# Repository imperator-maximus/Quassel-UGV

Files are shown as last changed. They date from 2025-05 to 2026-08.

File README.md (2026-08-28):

# 🚁 Quassel UGV - RTK-GPS + WitMotion Sensor Hub + WebApp

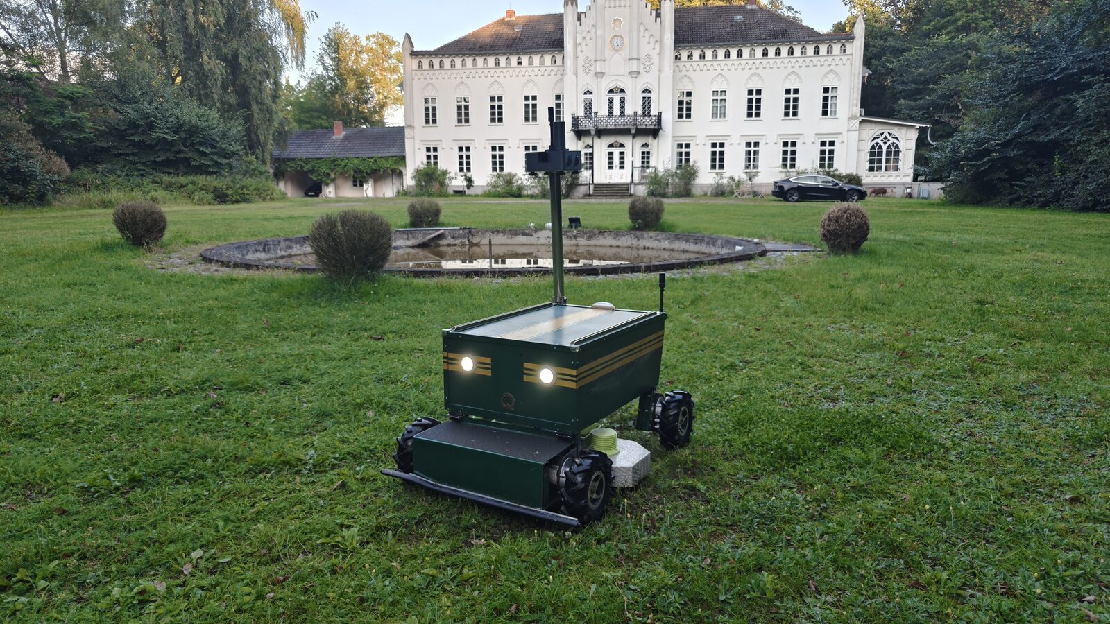
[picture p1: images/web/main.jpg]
Quassel UGV in the manor park


> Start here for the current vehicle: **[`CURRENT_PRODUCTION.md`](CURRENT_PRODUCTION.md)**
>
> More photos with descriptions: **[`images/README.md`](images/README.md)**

A professional autonomous UGV system with an Orange-Pi-based sensor hub, RTK-GPS positioning, WitMotion IMU orientation, redundant WiFi telemetry, direct ODrive USB control, and a real-time web interface.

> **Authoritative production state:** the GNSS receiver is attached to the
> Raspberry over USB serial and RTK corrections arrive by NTRIP. Both ODrive
> boards use two direct USB/Fibre links. The CAN bus and the separate SensorHub
> are removed, code included. Do not reintroduce either.
>
> Sections below that still describe the Orange Pi SensorHub are stale and
> await the physical details of the new arrangement.

## 🎯 Project Overview

This project implements a complete autonomous UGV system featuring:
- **Dual-antenna RTK-GPS** (Holybro UM982) for precise positioning and heading
- **WitMotion USB-IMU** for roll/pitch/yaw orientation
- **Direct ODrive USB control** with current, error and watchdog diagnostics
- **Redundant HTTP/WiFi SensorHub telemetry** over two persistent streams
- **Real-time Web Interface** with Bing Maps satellite view
- **Modular Architecture** with Orange Pi Zero 2W sensor hub and Pi 3 controller

### ✅ Project Status: **ACTIVE DEVELOPMENT**
- ✅ Sensor hub architecture (Orange Pi Zero 2W, RTK/IMU and WiFi telemetry)
- ✅ RTK-GPS + IMU integration
- ✅ Two direct ODrive USB/Fibre connections
- ✅ Web interface framework
- ✅ WitMotion-based IMU telemetry on the sensor hub

## 🏗️ System Architecture

### Hardware Architecture

```
┌─────────────────────────────────────────┐
│  MAST (Orange Pi Zero 2W)               │
│  ├─ Holybro UM982 (Dual-Antenna RTK)    │
│  │  └─ USB Serial (/dev/serial/by-id)   │
│  ├─ WitMotion USB-IMU                   │
│  │  └─ USB Serial (/dev/serial/by-id)   │
│  └─ SensorHub HTTP API                  │
└─────────────────────────────────────────┘
            │
            │ HTTP/WiFi telemetry
            ▼
┌─────────────────────────────────────────┐
│  CHASSIS (Pi 3 + Motor Control)         │
│  ├─ WebApp (Python-based)               │
│  ├─ 2× direct ODrive USB/Fibre          │
│  │  └─ 3 used axes by serial + index    │
│  └─ WLAN Access Point                   │
└─────────────────────────────────────────┘
            │
            │ WLAN
            ▼
    [ Browser-Client ]
```

### Production Transport Assignment

Everything hangs off the Raspberry directly. There is no bus and no second
computer in the loop.

| System | Active transport | Profile |
|---|---|---|
| GNSS receiver → Raspberry | USB serial | port via `/dev/serial/by-id` |
| RTK corrections → Raspberry | NTRIP over cellular | mountpoint `openrtk_mv` |
| Raspberry → ODrive boards | Two direct USB/Fibre links | serial number + axis index |

### Physical Vehicle Layout

- **Vehicle length**: approx. **115 cm**
- **Vehicle width incl. wheels**: approx. **79 cm**
- **Vehicle height without mast**: approx. **60 cm**
- **Additional mast height incl. enclosure**: approx. **70 cm**
- **Overall height with mast**: approx. **130 cm**
- **Payload / ride-on capability**: the platform is large and robust enough that **one person can ride on it**

**Sensor placement:**
- **Mast position**: rear left on the vehicle
- **Primary GPS antenna**: mounted on the mast, rear left, at approx. **130 cm** height
- **Secondary GPS antenna**: mounted rear right directly on the housing at approx. **60 cm** height
- **Distance between GPS antennas**: approx. **51 cm**
- **Side inset of both GPS antennas**: approx. **14 cm** inboard from the left/right vehicle edge
- **Rear inset of both GPS antennas**: approx. **10 cm** forward from the rear edge
- **IMU position**: mounted at the top of the mast

### Software Stack

**Orange Pi Zero 2W (Sensor Hub):**
| Component | Function | Interface |
|---|---|---|
| UM982 GPS | RTK Position + Dual-Antenna Heading | USB Serial /dev/serial/by-id |
| WitMotion USB-IMU | 9-DoF IMU incl. orientation frames | USB Serial |
| `sensor_hub_app.py` | Web API + redundant HTTP telemetry + sensor status | Systemd Service |

**Data Flow:**
- GPS-NMEA reading (pyserial)
- IMU data reading (pyserial / WitMotion binary protocol)
- Sensor telemetry (Position + Heading + Roll/Pitch/Yaw)
- Two persistent NDJSON telemetry streams over HTTP/WiFi

**Pi 3 (Controller + WebApp):**
| Component | Function |
|---|---|
| Python WebApp | Flask/FastAPI |
| ODrive USB/Fibre | Controls three axes and reads errors/current directly |
| SensorHub HTTP client | Receives RTK/IMU telemetry over WiFi |
| WebSocket/SSE | Real-time push to browser |
| Bing Maps API | Map display |

**WebApp Features:**
- 🗺️ Bing Maps Satellite View (Lübtheen-optimized)
- 📍 GPS Position (Live marker)
- 🧭 Heading Display (Dual-antenna)
- 📊 RTK Status (No Fix / Float / Fixed)
- 🛤️ Trail/Path (last N positions)
- 📐 Roll/Pitch/Yaw from IMU

## 🛠️ Development Tools (`tools/`)

Deployment and ODrive configuration utilities; see `tools/README.md`.

## 🚀 Quick Start

### 1. Install Dependencies on Raspberry Pi 3 (Controller)
```bash
# Install web framework and the GNSS serial dependency
pip3 install -r raspberry_pi/motor_controller/requirements.txt
```

### 3. Setup Sensor Hub (Orange Pi Zero 2W)
```bash
# Upload current sensor hub
scp -r sensor_hub nicolay@orangeugv:/home/nicolay/

# Follow the tested deploy guide
ssh nicolay@orangeugv
cd /home/nicolay/sensor_hub
sudo systemctl start sensor-hub.service
```

### 4. Setup Controller (Pi 3)
```bash
# Upload web app
scp web_app.py nicolay@raspberrycan:/home/nicolay/

# Start web interface
python3 web_app.py
# Access at http://raspberrycan:80
```

## 📋 Hardware Configuration

### Vehicle Geometry / Sensor Placement

- **Length**: approx. **115 cm**
- **Width incl. wheels**: approx. **79 cm**
- **Height without mast**: approx. **60 cm**
- **Mast incl. enclosure**: additional approx. **70 cm**
- **Mast location**: **rear left**
- **Upper GPS antenna**: rear left on mast, approx. **130 cm** above ground
- **Lower GPS antenna**: rear right on housing, approx. **60 cm** above ground
- **GPS antenna baseline**: approx. **51 cm**
- **Lateral antenna inset**: approx. **14 cm** from each outer side edge (`(0.79 m - 0.51 m) / 2`)
- **Rear antenna inset**: approx. **10 cm** from the rear edge
- **IMU**: mounted on top of the mast
- **Ride-on capability**: one person can ride on the vehicle

### Sensor Hub (Orange Pi Zero 2W)
- **MCU**: Allwinner H616
- **GPS**: Holybro UM982 (Dual-antenna RTK)
  - USB serial via `/dev/serial/by-id/...`
- **IMU**: WitMotion USB-IMU
  - USB serial via `/dev/serial/by-id/...`
- **Operating System**: DietPi / Debian-based
- **Network**: HTTP/WiFi to the Raspberry controller via the Fritzbox port forward

### Controller (Pi 3)
- **MCU**: Broadcom BCM2837 (ARM Cortex-A53 Quad-Core)
- **Mower interface**: two direct USB/Fibre links to ODrive Board A/B
- **Motor Control**: GPIO 18/19 (Hardware-PWM)
- **Operating System**: Raspberry Pi OS (Debian-based)
- **Network**: WiFi + SSH access (nicolay@raspberrycan)

### Sensor Hub Device Usage (Orange Pi Zero 2W)
**USB Devices:**
- **Holybro UM982**: USB serial GNSS (`/dev/serial/by-id/...`)
- **WitMotion IMU**: USB serial IMU (`/dev/serial/by-id/usb-1a86_USB_Serial-if00-port0`)

### GPIO Pin Configuration (Pi 3 - Controller)
**Motor Control:**
- **GPIO 18**: Right Motor PWM Output (Hardware-PWM)
- **GPIO 19**: Left Motor PWM Output (Hardware-PWM)

**Relay Control:**
- **GPIO 22**: Light Control Relay Output (HIGH = On, LOW = Off)
- **GPIO 23**: Mower Control Relay Output (HIGH = On, LOW = Off)

**Safety:**
- **GPIO 17**: Emergency Stop/Safety Switch Input (pulled high, active low)
- **GPIO 12**: Mower Speed PWM Output (24-100% Duty Cycle, 1000Hz, 3.3V GPIO)

### Mower Speed Control (PWM-to-Analog Conversion)

The mower speed control uses PWM-to-analog conversion via RC filter circuit:

**Circuit Configuration:**
```
GPIO12 (PWM) ----[1kΩ]----+-----> Analog Output (to Mower Controller)
                           |
                         [15µF]
                           |
                         GND
```

**PWM Specifications:**
- **Frequency**: 1000Hz
- **Duty Cycle Range**: 24-100% (optimized for 3.3V GPIO)
- **Output Voltage Range**: 0.8V - 3.3V
- **Speed Mapping**: 0% = 0.8V (idle), 100% = 3.3V (full speed)

**RC Filter Analysis:**
- **Time Constant**: τ = 1kΩ × 15µF = 15ms
- **Smoothing Factor**: 15x PWM period (excellent filtering)
- **Ripple**: <1% of output voltage

## 🔧 Key Features

### Sensor Integration
- **Dual-Antenna RTK-GPS** (Holybro UM982)
  - Precise positioning (cm-level accuracy)
  - Dual-antenna heading (no compass needed)
  - NMEA output via UART
- **WitMotion USB-IMU**
  - Accelerometer + Gyroscope + orientation frames
  - Roll/Pitch/Yaw orientation
  - USB serial interface

### Sensor Hub Telemetry
- **Real-time position tracking** with RTK-GPS
- **Heading calculation** from dual-antenna GPS
- **Native orientation data** from the WitMotion IMU
- **Redundant HTTP/WiFi streaming** to the controller

### Web Interface
- **Bing Maps satellite view** (Lübtheen-optimized)
- **Live GPS marker** with real-time updates
- **Heading indicator** (dual-antenna)
- **RTK status display** (No Fix / Float / Fixed)
- **Trail visualization** (last N positions)
- **Roll/Pitch/Yaw display** from IMU
- **WebSocket real-time updates** (50Hz)

### Motor Control
- **2-channel Hardware-PWM output** (1000-2000μs pulse width)
- **Freeze-resistant PWM generation** using pigpio hardware timers
- **Real-time monitoring** with live percentage and PWM display
- **Intelligent Ramping System** for smooth acceleration and quick braking

### Safety Features
- **Hardware-PWM independence** (continues running if Python crashes)
- **Command timeout monitoring** (2-second timeout → automatic neutral)
- **Emergency stop functionality** with signal handlers
- **Two-stage SensorHub fail-safe**: a short telemetry loss pauses drive and
  route while leaving the mower deck running; a sustained loss latches the
  full stop. An autonomous route resumes automatically after fresh telemetry;
  ODrive USB loss still stops immediately.
- **Mower overcurrent monitor**: native USB telemetry is polled at 10 Hz for
  nodes 0/1/2; 25 A for 0.5 s or 29 A for 0.1 s latches the same stop
- **Local ODrive watchdog**: each used axis must have a 1.0 s watchdog enabled,
  so the mower disarms even when a broken USB link prevents an IDLE command
- **Manual reset**: the web UI shows `STOPP`; reset is accepted only after the
  all USB axes are healthy and no non-watchdog ODrive error remains
- **Service integration** with automatic restart on failure

## 🎮 System Commands

### Sensor Hub (Orange Pi Zero 2W)
```bash
# Start sensor hub service
sudo systemctl start sensor-hub.service

# View sensor data
sudo systemctl status sensor-hub.service

# Verify the local telemetry stream
curl -N --max-time 3 http://127.0.0.1/api/telemetry/stream

# View logs
journalctl -u sensor-hub -f
```

### Controller (Pi 3)
```bash
# Start web interface
python3 web_app.py

# Access web interface
# http://raspberrycan:80

# Inspect USB ODrive and SensorHub stream status
curl http://127.0.0.1/api/status

# View application logs
tail -f /var/log/ugv_app.log
```

## 📊 System Communication Flow

```
Sensor Hub (Orange Pi Zero 2W)   Main UGV Controller (Pi 3)
├─ GPS (UM982)                   ├─ Web Interface
├─ IMU (WitMotion USB)           ├─ Vehicle PWM control
└─ HTTP telemetry ─── WiFi ─────┤
                                 ├─ USB ─ ODrive Board A (axes 0/1)
                                 └─ USB ─ ODrive Board B (axis 0)
                        │
                        ▼
                  [ Browser Client ]
                  (Bing Maps + RTK)
```

## 🗂️ Project Structure

```
UGV ESP32CAN/
├── 📄 README.md                    # This documentation
├── 📁 sensor_hub/                 # Current sensor hub (Orange Pi Zero 2W)
│   ├── sensor_hub_app.py          # Flask API + HTTP/WiFi telemetry
│   ├── imu_handler.py             # WitMotion USB IMU parser
│   ├── sensor-hub.service         # systemd service file
│   ├── templates/sensor_hub.html  # Sensor hub web interface
│   └── README.md                  # Detailed usage guide
├── 📁 raspberry_pi/               # Controller and legacy Raspberry Pi docs
│   ├── motor_controller/          # Current controller implementation
│   └── README.md                  # Controller / legacy setup notes
├── 📁 tools/                      # Deployment and configuration
└── 📁 archive/                    # Development history
    ├── 📁 esp32_files/            # Legacy ESP32 implementation
    ├── 📁 beyond_robotics_working/ # Legacy Beyond Robotics code
    ├── 📁 development_scripts/    # Development utilities
    └── 📁 old_documentation/      # Historical documentation
```

## 🧪 Testing and Validation

### Unit Tests

The repository ships with hardware-independent unit tests that cover the
non-trivial math and state machines on both Pis. They run in well under a second
and **must be kept green**; they are the regression safety net for the
navigation pipeline. Do not delete them.

**Location and coverage:**

| Test file | Covers |
|---|---|
| `sensor_hub/tests/test_vehicle_geometry.py` | Lever-arm correction (`correct_to_vehicle_center`): rotates the antenna offset by the current heading and translates the GPS fix to the vehicle center. A sign error here desyncs the map marker, the transmitted telemetry pose, and the navigation distance calculation. |
| `sensor_hub/tests/test_telemetry_payload.py` | Heading source priority in the telemetry payload: dual-GNSS heading wins over the IMU fallback, `heading_source` field reports `dual_gnss` / `imu_fallback`, and the raw GPS heading stays available under `gps.heading` for diagnostics. |
| `raspberry_pi/motor_controller/tests/test_navigation_controller.py` | `NavigationController` end-to-end: bearing/heading-error wrapping, 30%-joystick limit, transport-independent telemetry pose ingestion, geofence stop, watchdog stop, `nav_*` command dispatch, **acceptance-radius arrival**, the **overshoot detector** (waypoint counts as reached when the minimum distance was within `engagement_radius = max(3 × acceptance_radius_m, 1.5 m)` and grows again for ≥2 consecutive samples — including a tangential grazing-pass case), and the **inner-wheel-speed guarantee** (anti-pivot floor scaled by `heading_factor = max(0, 1 − |err|/90°)`: at moderate errors the inner wheel rolls forward out of the ESC dead-zone; at ≥90° the floor collapses to 0 so the robot can pivot tightly without scrubbing; the `forward ≥ |turn|·ratio` no-reverse guard always holds). The overshoot test is the regression guard against the endless-pivot bug that occurs when GPS noise + drivetrain inertia keep the vehicle just outside the acceptance circle. |

**Running the suite (from repo root):**

```bash
# One-time local test setup, including Windows-safe geometry dependencies
python -m pip install -r requirements-dev.txt

# Motor-Controller tests
python -m unittest discover -s raspberry_pi/motor_controller/tests -v
```

The suite is pure-Python (no GPIO, no GPS hardware), so it runs on any
developer machine — including Windows. `shapely` is included in the dev
requirements so the mowing-lane geometry tests run instead of being skipped.
CI / pre-deploy: run it before any deploy to `raspberrycan`.

**When adding new behavior to the navigation or geometry code, extend the
existing test files rather than creating throwaway ad-hoc scripts.**

**Motor-controller deploy from Windows:**

```powershell
.\tools\deploy_motor_controller.ps1
```

The script uploads the motor-controller code, web template, and static assets
to `raspberrycan`, preserves the remote `config.yaml`, creates a timestamped
backup under `/home/nicolay/backup/`, restarts `motor-controller-v2.service`,
waits for the web server to answer, and checks `/` plus `/api/status`.

Tests are opt-in and deliberately not part of every deploy: `-Tests` runs both
suites locally (under a minute), `-RemoteTests` additionally runs them on the Pi
(about ten minutes — for when dependencies or the device Python changed).

**Mapping UI browser smoke test:**

```bash
npm install
npm run smoke:mapping-ui
```

Set `UGV_BASE_URL=http://raspberrycan` to target another host. The smoke test
loads the UI in Chromium, opens the Karten tab, verifies the extracted
`mapping_editor.js` asset, checks the expected mapping globals, and fails on
browser console errors or failed network requests.

### System Integration Test
```bash
# 1. Setup Sensor Hub (Orange Pi Zero 2W)
ssh nicolay@raspberrycan
./setup_sensor_hub.sh
source ~/.bashrc

# 2. Check sensor hub status
sudo systemctl status sensor-hub

# 3. Verify the production telemetry stream
curl -N --max-time 3 http://orangeugv/api/telemetry/stream

# 4. Start web interface (Pi 3)
python3 web_app.py

# 5. Access web interface
# http://raspberrycan:80
```

### Expected Output
**Sensor Hub Service:**
```
[15:33:41] 📡 GPS Position: 53.8234°N, 10.4567°E
[15:33:41] 🧭 Heading: 45.2° (Dual-Antenna)
[15:33:41] 📊 RTK Status: FIXED
[15:33:41] 📐 Roll: +2.3°, Pitch: -1.8°
[15:33:41] 🌐 HTTP telemetry stream active
```

**Web Interface:**
```
✅ Connected to Sensor Hub
📍 Position: 53.8234°N, 10.4567°E
🧭 Heading: 45.2°
📊 RTK: FIXED
🛤️ Trail: 42 points
```

## 🔧 Configuration Options

### Sensor Hub Settings (`sensor_hub/config.py`)
```python
# GPS Configuration
GPS_PORT = '/dev/serial/by-id/usb-FTDI_FT231X_USB_UART_*'
GPS_BAUDRATE = 230400            # UM982 baud rate

# IMU Configuration
IMU_TYPE = 'witmotion'
IMU_PORT = '/dev/serial/by-id/usb-1a86_USB_Serial-if00-port0'
IMU_BAUDRATE = 9600

# Production telemetry
WEB_PORT = 80
# /api/telemetry/stream emits compact NDJSON at approximately 5 Hz
```

### Web App Settings (`web_app.py`)
```python
# Flask Configuration
FLASK_HOST = '0.0.0.0'           # Listen on all interfaces
FLASK_PORT = 80                  # HTTP port
DEBUG = False                    # Production mode

# WebSocket Configuration
UPDATE_RATE = 50                 # Hz (20ms updates)
WEBSOCKET_TIMEOUT = 30           # Seconds
```

### Navigation Tuning (`raspberry_pi/motor_controller/config.yaml`)

```yaml
navigation:
  max_joystick: 0.30           # Hard cap on joystick magnitude (30 % scale)
  acceptance_radius_m: 0.25    # Waypoint reached when distance ≤ this value
  slowdown_radius_m: 0.5       # Linear throttle ramp-down toward 0 inside this radius
  turn_kp: 0.02                # Joystick-X per degree of heading error
  min_inner_wheel_speed: 0.50  # Anti-pivot inner-wheel guarantee (fraction of max_joystick)
```

**`acceptance_radius_m` (0.25 m)** — primary arrival criterion. Tightened from the
RTK-theoretical 10 cm to 25 cm to account for skid-steer drift + drivetrain inertia.
Combined with the overshoot detector (see below) the robot reliably terminates the
final waypoint instead of orbiting it.

**Overshoot detector (implicit)** — derived in code as
`engagement_radius = max(3 × acceptance_radius_m, 1.5 m)`. Once the vehicle has
been within this radius and the distance to the target grows again for ≥2
consecutive samples (with a 3 cm jitter tolerance against RTK noise), the
waypoint is counted as reached even if the acceptance circle was never entered.
This is the regression-guarded fix for the endless-pivot bug.

**`min_inner_wheel_speed` (0.50)** — anti-pivot guarantee. The inner (turn-side)
wheel must roll forward with at least `min_inner_wheel_speed × max_joystick`,
which puts the inner ESC ~75 µs above neutral, safely outside the dead-zone.
The robot then drives an arc instead of pivoting in place, which prevents
ground tearing on grass. The floor is scaled by
`heading_factor = max(0, 1 − |heading_error| / 90°)`: at small/moderate errors
the floor is fully active (smooth arc); at ≥90° error the floor collapses to 0
so the robot can pivot tightly without scrubbing while the always-on
`forward ≥ |turn| · ratio` guard still prevents the inner wheel from running
in reverse. Set to `0.0` to restore legacy pivot behaviour.

### Service Configuration (`sensor-hub.service`)
```ini
[Service]
ExecStart=/usr/bin/python3 /home/nicolay/sensor_hub/sensor_hub_app.py
Restart=always
RestartSec=5
User=nicolay
```

## 🐛 Troubleshooting

### Common Issues

#### ❌ "Sensor Hub service not starting"
**Cause**: Dependencies or permissions issue
**Solution**:
1. Check serial devices: `ls /dev/serial/by-id/`
2. Check service logs: `journalctl -u sensor-hub.service -f`
5. Restart service: `sudo systemctl restart sensor-hub`

#### ❌ "GPS not receiving data"
**Cause**: UART configuration or GPS hardware issue
**Solution**:
1. Check UART connection: `cat /dev/serial0` (should show NMEA data)
2. Verify baud rate: 230400 for UM982
3. Check GPS power supply
4. Test with: `python3 -c "import serial; s=serial.Serial('/dev/serial0', 230400); print(s.readline())"`

#### ❌ "IMU not responding"
**Cause**: USB serial device or IMU communication failure
**Solution**:
1. Check device path: `ls /dev/serial/by-id/`
2. Verify the WitMotion symlink exists
3. Confirm configured baudrate is `9600`
4. Check service logs: `journalctl -u sensor-hub.service -n 50`

#### ❌ "Web interface not accessible"
**Cause**: Flask or network issue
**Solution**:
1. Check Flask is running: `ps aux | grep web_app.py`
2. Verify port 80: `sudo netstat -tlnp | grep :80`
3. Check firewall: `sudo ufw status`
4. Test locally: `curl http://localhost:80`
5. Check logs: `tail -f /var/log/ugv_app.log`

### Debug Tools

#### Service Management
```bash
# Check sensor hub status
sudo systemctl status sensor-hub.service

# View live logs
journalctl -u sensor-hub.service -f

# Stop for manual testing
sudo systemctl stop sensor-hub.service
python3 sensor_hub/sensor_hub_app.py

# Restart service
sudo systemctl restart sensor-hub.service
```

#### Hardware Testing
```bash
# Test GPS
ls /dev/serial/by-id/

# Test IMU
curl http://127.0.0.1:8080/api/imu/status

# Monitor web app
tail -f /var/log/ugv_app.log
```

## 📈 Performance Characteristics

### System Specifications
- **Sensor Update Rate**: 50 Hz (20ms)
- **GPS Accuracy**: RTK Fixed (cm-level)
- **Heading Accuracy**: Dual-antenna (±1°)
- **IMU Sampling**: 200 Hz (5ms)
- **Memory Usage**: Python runtime (~80MB RAM)

### Communication Latency
- **Pose → Web Interface**: <100ms (WebSocket)
- **Web Interface Update**: 20ms (50Hz)

## 🔄 Development History

This project evolved from an Orange Cube-based implementation to the current RTK-GPS + WitMotion sensor hub system:

### Phase 1: ESP32 Prototype (`archive/esp32_files/`)
- Initial CAN implementation attempts
- CAN bus communication challenges
- Multiple timeout and reset issues

### Phase 2: RTK-GPS + WitMotion Sensor Hub (Current)
- Switched to Holybro UM982 dual-antenna RTK-GPS
- Added WitMotion USB-IMU
- Replaced legacy I2C fusion path with native WitMotion orientation frames
- Created web interface with Bing Maps
- Achieved superior positioning and orientation capabilities

## 🤝 Contributing

### Code Standards
- **Python**: PEP 8 compliance
- **Documentation**: Comprehensive inline comments
- **Testing**: Validate all changes with hardware
- **Git**: Clear commit messages with feature descriptions

### Development Workflow
1. **Test on hardware** - Always validate with real Raspberry Pi and sensors
2. **Use service management** - Stop service before testing new versions
3. **Document changes** - Update README and inline comments
4. **Archive old code** - Remove obsolete files or move them to archive/

## 📞 Support and Resources

### Official Documentation
- **Raspberry Pi Foundation**: https://www.raspberrypi.org/documentation/
- **Holybro UM982**: https://holybro.com/products/um982-rtk-gnss-receiver
- **WitMotion Protocol**: https://wit-motion.gitbook.io/witmotion-sdk/wit-standard-protocol/wit-standard-communication-protocol
- **pigpio Library**: http://abyz.me.uk/rpi/pigpio/

### Hardware Support
- **Orange Pi Zero 2W**: Allwinner H616 sensor hub with HTTP/WiFi telemetry
- **Raspberry Pi 3**: ARM Cortex-A53 Quad-Core
- **ODrive**: v3.x motor controllers, directly controlled over USB on the main UGV
- **Holybro UM982**: Dual-antenna RTK-GPS receiver
- **WitMotion USB-IMU**: IMU sensor with native orientation output

### Community
- **Raspberry Pi Community**: https://www.raspberrypi.org/forums/
- **RTK-GPS Community**: Holybro and u-blox forums

---

## 🎯 Project Status Summary

**🔄 ACTIVE DEVELOPMENT** - This RTK-GPS + WitMotion autonomous UGV system is under active development with a modular architecture featuring dual-antenna positioning, USB-based sensor ingestion, and real-time web interfaces.

**Key Achievements:**
- ✅ Sensor hub architecture (Orange Pi Zero 2W + redundant WiFi telemetry)
- ✅ Main UGV controller with two direct ODrive USB/Fibre links
- ✅ RTK-GPS + IMU integration
- ✅ Redundant JSON/NDJSON telemetry over HTTP/WiFi
- ✅ Web interface framework with motor control
- ✅ WitMotion-based IMU telemetry on the sensor hub

**Communication Architecture:**
- **Sensor Hub → Controller**: two persistent NDJSON streams over HTTP/WiFi
- **Controller → ODrives**: two direct USB/Fibre links
- **Web Interface**: WebSocket for real-time updates and joystick control
- **Safety**: short WiFi loss pauses driving; prolonged loss latches a system stop

**Current Focus:**
- 🗺️ Bing Maps satellite view integration
- 📍 Real-time GPS position tracking
- 🧭 Dual-antenna heading calculation
- 📊 RTK status monitoring
- 🛤️ Trail visualization
- 📐 IMU-based orientation display
- 🎮 Web-based joystick control with USB/stream status diagnostics

The project is actively being developed with focus on autonomous navigation capabilities and robust communication.

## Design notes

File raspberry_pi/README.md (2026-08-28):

# 🚀 Quassel UGV - Sensor Hub & Motor Controller v2.0

**RTK-GPS + USB-IMU telemetry with real-time web interface for autonomous UGV**

> **Produktionsstand 24.07.2026:** SensorHub-Pose ueber zwei parallele
> HTTP/WiFi-Streams; beide ODrive-Boards ueber zwei direkte USB/Fibre-Kabel.
> CAN-Bus und SensorHub sind ausgebaut, ihr Code ist entfernt.

## 🎯 Project Overview

**Goal:** Implement autonomous UGV with RTK-GPS positioning, IMU orientation, and real-time web interface.

**Hardware:**
- **GNSS**: Holybro UM982 per USB seriell am Raspberry
  - Holybro UM982 (Dual-antenna RTK-GPS, USB)
  - WitMotion USB-IMU (USB)
- **Motor Controller**: Raspberry Pi 3 + zwei direkte ODrive-USB-Verbindungen
  - Motor control (2-channel Hardware-PWM via pigpio)
  - Mower control (Relay + PWM speed control)
  - Light control (Relay)
  - Safety switch (Emergency stop)
  - Web interface with virtual joystick

**Communication:**
- SensorHub → Raspberry: zwei persistente HTTP/WiFi-NDJSON-Streams
- Raspberry → ODrives: direkte USB/Fibre-Verbindungen nach Seriennummer/Achse
- GNSS → Raspberry: USB seriell; RTK-Korrekturen per NTRIP
- IMU/GPS telemetry updates
- WebSocket: Real-time web interface

## 📁 Architektur

```
motor_controller/
├── __init__.py              # Package-Initialisierung
├── main.py                  # Entry Point
├── config.py                # Konfigurationsverwaltung
├── config.yaml.example      # Beispiel-Konfiguration
├── hardware/
│   ├── __init__.py
│   ├── gpio_controller.py   # GPIO-Verwaltung (Singleton)
│   ├── pwm_controller.py    # PWM-Steuerung (Motoren + Mäher)
│   └── safety_monitor.py    # Sicherheitsüberwachung + Watchdog
├── communication/
│   ├── __init__.py
│   ├── pose_cache.py        # Zwischenspeicher der GNSS-Pose
│   └── can_protocol.py      # Multi-Frame JSON-Protokoll
├── control/
│   ├── __init__.py
│   ├── motor_control.py     # Motor-Logik (Skid Steering + Ramping)
│   └── joystick_handler.py  # Joystick-Verarbeitung
└── web/
    ├── __init__.py
    └── web_server.py         # Flask Web-Interface
```

## 🚀 Quick Setup

### 1. Sensor Hub Setup (Pi Zero 2W)
```bash
# Follow the current Orange Pi deploy guide
cd ../sensor_hub
less DEPLOY_ORANGE_PI.md
```

### 2. Motor Controller Setup (Pi 3) - v2.0

#### **Installation**
```bash
# Dependencies installieren
pip3 install pyyaml pyserial RPi.GPIO pigpio Flask

# pigpiod aktivieren
sudo systemctl enable pigpiod
sudo systemctl start pigpiod

# Verzeichnis erstellen
mkdir -p /home/nicolay/motor_controller

# Dateien kopieren (aus Repository)
cp -r raspberry_pi/motor_controller/* /home/nicolay/motor_controller/
```

#### **Konfiguration**
```bash
# Beispiel-Config kopieren
cp /home/nicolay/motor_controller/config.yaml.example \
   /home/nicolay/motor_controller/config.yaml

# Config anpassen
nano /home/nicolay/motor_controller/config.yaml
```

#### **Manueller Test**
```bash
cd /home/nicolay/motor_controller
python3 -m motor_controller.main --config config.yaml

# Oder mit Legacy CLI-Args
python3 -m motor_controller.main --pwm --pins 18,19 --web
```

#### **Systemd-Service**
```bash
# Service installieren
sudo cp motor_controller_v2.service /etc/systemd/system/
sudo systemctl daemon-reload
sudo systemctl enable motor-controller-v2.service
sudo systemctl start motor-controller-v2.service

# Status prüfen
sudo systemctl status motor-controller-v2.service

# Logs anzeigen
sudo journalctl -u motor-controller-v2.service -f
```

#### **Web-Interface**
```bash
# Zugriff über Browser
http://raspberrycan/

# API-Status
curl http://raspberrycan/api/status
```

### 3. Produktive Hardware-Verbindungen

- Der GNSS-Empfaenger haengt per USB am Raspberry; kein Bus, kein zweiter Rechner.
- ODrive Board A und B sind jeweils direkt per USB mit dem Raspberry verbunden.
- CAN-Klemmen, USB-CAN-Adapter und CAN HAT sind ausgebaut.

## 🔧 Hardware Configuration

### Sensor Hub (Orange Pi Zero 2W) Boot Configuration
```bash
# Der separate SensorHub ist ausgebaut. Der GNSS-Empfaenger haengt
# direkt am Raspberry; der Port steht in config.yaml unter pose.gps_port.
```

### Controller (Pi 3) Boot Configuration
```bash
# /boot/firmware/config.txt
# Kein MCP2515-CAN-Overlay noetig.
```

The retired InnoMaker HAT and its `mcp2515-can*` Device Tree overlay are no
longer used. SPI may remain enabled for unrelated peripherals.

### Sensor Configuration
**GPS (Holybro UM982):**
- UART: /dev/serial0
- Baud Rate: 230400
- Output: NMEA sentences

**IMU (WitMotion USB):**
- Port: `/dev/serial/by-id/usb-1a86_USB_Serial-if00-port0`
- Baudrate: 9600
- Sampling Rate: 200 Hz

## 📁 Project Files

```
raspberry_pi/
├── motor_controller/              # Current Raspberry Pi 3 controller
├── web_app.py                     # Web interface (Pi 3)
├── setup_sensor_hub.sh            # Older Raspberry Pi sensor hub setup script
├── install_web_dependencies.sh    # Web interface setup
├── templates/index.html           # Web interface template
├── README.md                      # This documentation
└── sensor-hub.service             # Historical Raspberry Pi service example
```

## 🧪 Testing & Validation

### 1. Sensor Hub Validation
```bash
# Check WitMotion USB device
ls /dev/serial/by-id/
# Expected: usb-1a86_USB_Serial-if00-port0

# Check UART GPS
cat /dev/serial0
# Expected: NMEA sentences from UM982

```

### 2. Sensor Hub Service
```bash
# Start sensor hub service
sudo systemctl start sensor-hub

# Check status
sudo systemctl status sensor-hub

# View logs
journalctl -u sensor-hub -f
```

### 3. Web Interface
```bash
# Start web interface
python3 web_app.py

# Access at http://raspberrycan:80
```

## 🔍 Troubleshooting

### GPS Not Receiving Data
```bash
# Check UART connection
cat /dev/serial0

# Verify baud rate: 230400 for UM982
python3 -c "import serial; s=serial.Serial('/dev/serial0', 230400); print(s.readline())"
```

### IMU Not Responding
```bash
# Check USB serial devices
ls /dev/serial/by-id/
# Should show usb-1a86_USB_Serial-if00-port0

# Check live IMU status from the sensor hub
curl http://127.0.0.1:8080/api/imu/status
```

### Web Interface Not Accessible
```bash
# Check Flask is running
ps aux | grep web_app.py

# Verify port 80
sudo netstat -tlnp | grep :80

# Test locally
curl http://localhost:80
```

## 📈 Performance Characteristics

### System Specifications
- **Sensor Update Rate**: 50 Hz (20ms)
- **GPS Accuracy**: RTK Fixed (cm-level)
- **Heading Accuracy**: Dual-antenna (±1°)
- **IMU Sampling**: 200 Hz (5ms)
- **Memory Usage**: Python runtime (~80MB RAM)

### Communication Latency
- **Pose → Web Interface**: <100ms (WebSocket)
- **Web Interface Update**: 20ms (50Hz)

## 🎉 Success Criteria

### Hardware Setup Complete
- ✅ WitMotion USB device detected
- ✅ UART GPS receiving NMEA data

### Sensor Hub Telemetry Working
- ✅ GPS position updates at 50 Hz
- ✅ IMU orientation data available
- ✅ Web interface displays real-time data

## 🚀 Ready for Production

Once setup is complete, the system provides:
- **Precise RTK-GPS positioning** (cm-level accuracy)
- **Dual-antenna heading** without compass
- **6-DoF orientation** from WitMotion IMU
- **Real-time web interface** with Bing Maps
- **Autonomous navigation** capabilities

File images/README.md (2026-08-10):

# Image Gallery — Quassel UGV

Photos of the production vehicle, taken on 2026-08-10 in the manor park at
Lübtheen. All descriptions below are limited to what is actually visible in the
photo; no dimensions or mounting positions are inferred from the pictures.

Every picture below is shown as a **1600 px web version** from `web/`
(EXIF stripped, ~0.4 MB each) and links to the **full-resolution original**
(4096 px, 4–7 MB) in this directory. Use the originals for print or detail
work, the web versions everywhere a page has to load quickly.

---

## `main.jpg` — Title image: front view in the park

Front view of the Quassel UGV

The vehicle seen head-on from a low angle on the lawn, with the manor house and
the round ornamental basin behind it. The dark green body carries two gold
stripes on each side of the front panel, two round LED headlights (switched on)
and the gold `Q` marque below them. The mast rises from the vehicle body and
carries the sensor enclosure at its top; a white dome antenna and a short black
whip antenna sit on the upper deck of the body. The mowing deck with its front
skid bar is attached ahead of the body, and the knobbly tyres on their direct
hub drives are visible on both sides. This is the reference shot used as the
repository title image.

---

## `IMG20260810194808.jpg` — Side view with raised mast

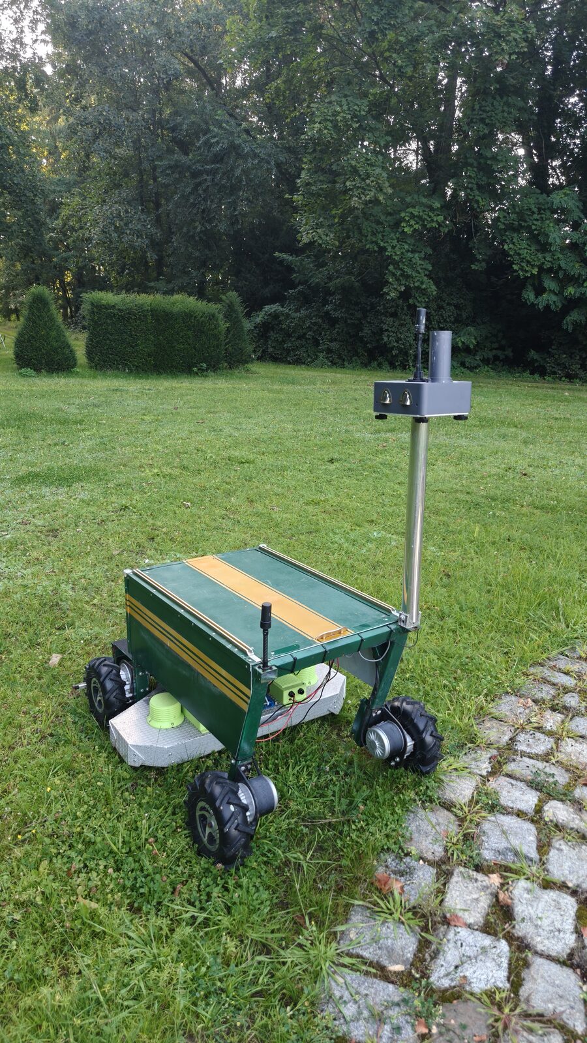
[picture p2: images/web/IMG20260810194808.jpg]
Side view with raised mast


Portrait shot from the rear left on the lawn next to a cobbled path. The full
height of the mast is visible: a polished tube, braced diagonally against the
body, carrying the grey sensor enclosure with two lenses in its front face, a
short black antenna and a larger black cylinder on top. Underneath the body the
open equipment bay shows the light-green modules and the red/black power
harness; the wheels with their direct hub motors are shown unobstructed. Good
overview of the overall proportions of chassis, drive and mast.

---

## `IMG20260810194830.jpg` — Top view of the body cover

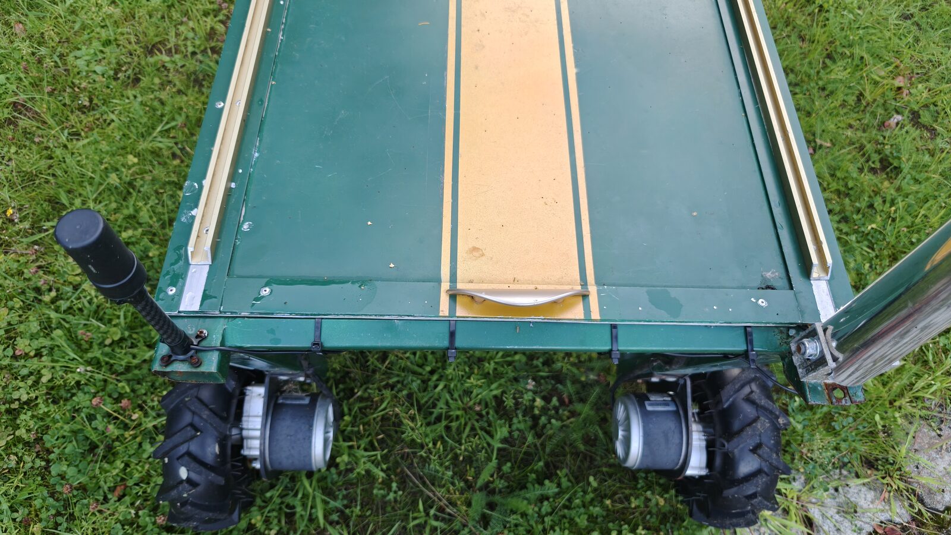
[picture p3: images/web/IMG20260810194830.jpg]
Top view of the body cover


Close-up looking down at the upper deck. The green cover panel with the gold
centre stripe, the aluminium edge rails and the recessed pull handle are
clearly visible, as are the cable ties along the rear edge and the clamped
foot of the mast on the right-hand edge. Below the rear edge two wheels with
their hub motors and motor cabling can be seen. Useful as a detail shot of the
cover, its mechanical fixings and the cable routing.

---

## `IMG20260810195032.jpg` — Wide shot: vehicle in front of the manor

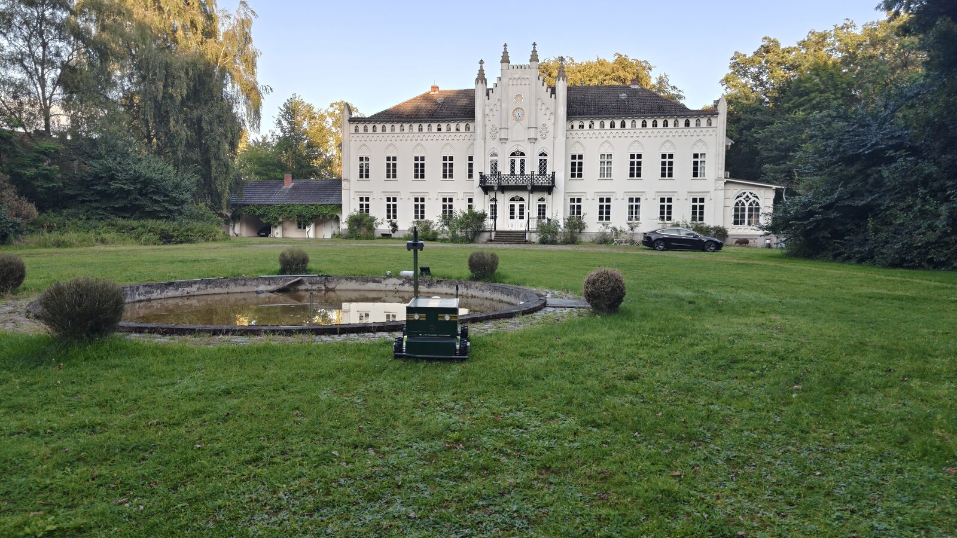
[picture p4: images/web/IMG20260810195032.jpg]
Wide shot of the vehicle in front of the manor


Wide landscape view of the whole scene. The neo-Gothic manor with its central
tower and clock forms the background, the empty round basin the middle ground,
and the UGV stands small and centred on the cobbled apron at the rim of the
basin. Shows the working environment and the scale of the mowing area rather
than the vehicle itself.

---

## `IMG20260810195101.jpg` — Wide shot: vehicle at the basin, headlights on

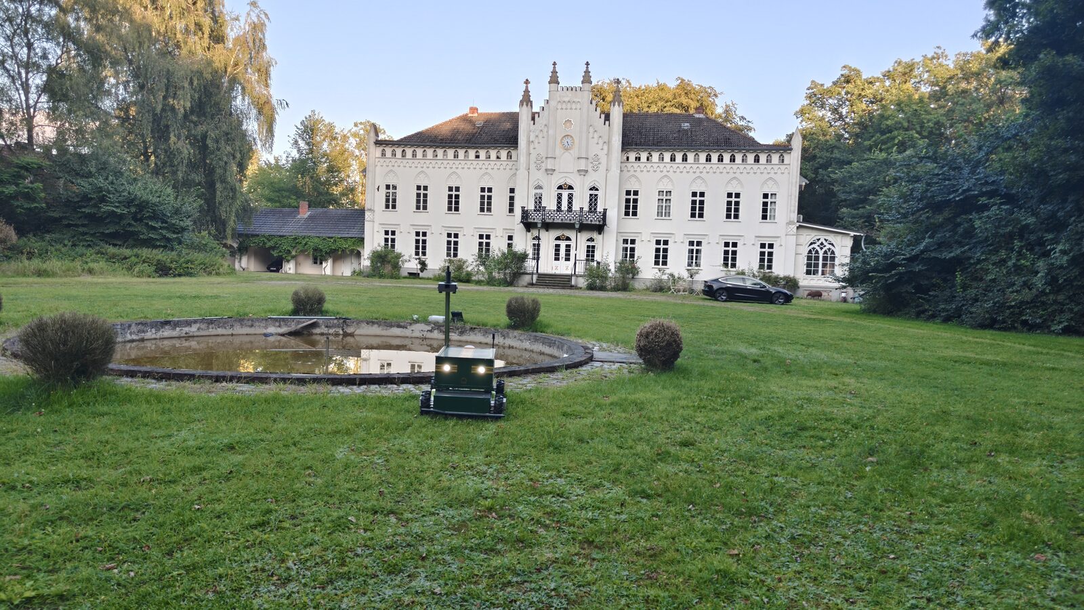
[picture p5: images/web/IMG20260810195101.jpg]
Vehicle at the basin with headlights on


Same viewpoint as the previous shot but closer and with the headlights lit. The
vehicle sits at the edge of the basin on the cobbled ring, mast up. The lawn in
the foreground shows the mown surface the system operates on, and the basin
edge and the shrubs around it are exactly the kind of obstacles the geofence
and no-go zones must keep the vehicle away from.

---

## `IMG20260810195126.jpg` — Vehicle on the lawn in front of the basin

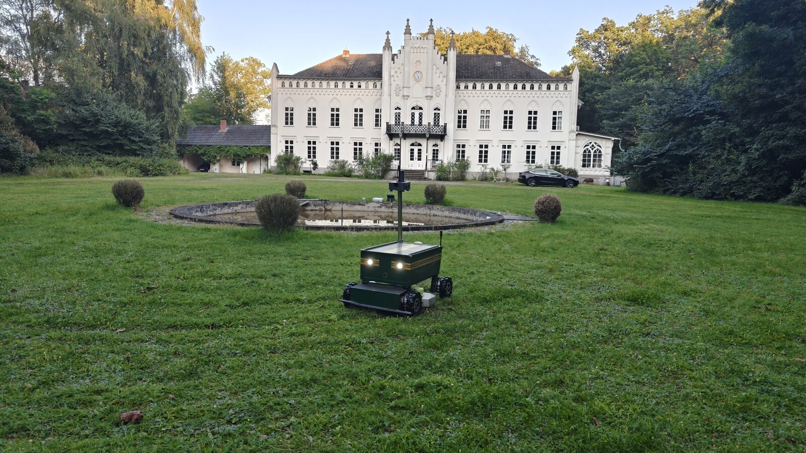
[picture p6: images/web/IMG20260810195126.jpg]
Vehicle on the lawn in front of the basin


Landscape shot from further forward. The UGV stands free on the grass ahead of
the basin, seen from the front left with both headlights on, mast raised and
sensor enclosure at the top. The manor, the basin and the ring of clipped
shrubs are all in frame, which makes this the clearest picture of the vehicle
in its operating context.

---

## `IMG20260810195204.jpg` — Rear three-quarter view on the open lawn

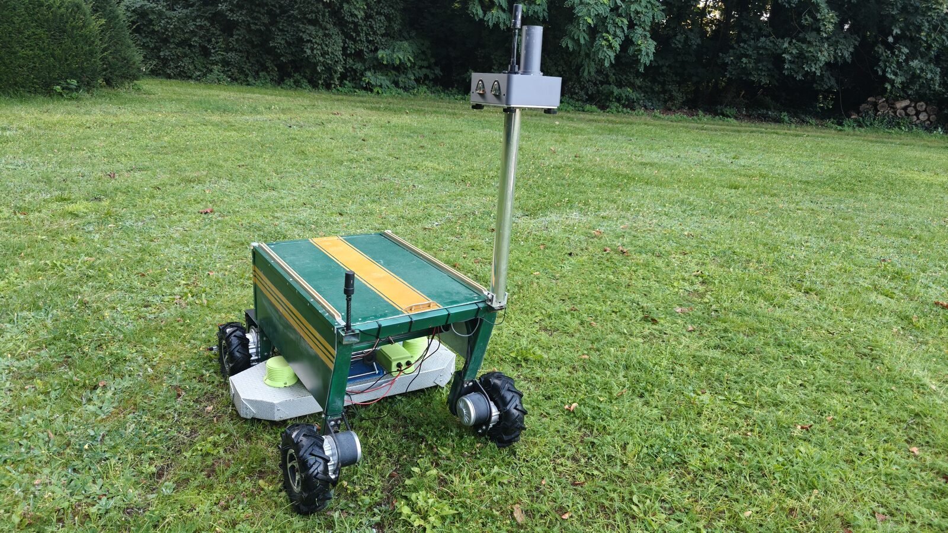
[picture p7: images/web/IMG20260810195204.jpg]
Rear three-quarter view on the open lawn


The vehicle photographed from the rear right on an open patch of lawn in front
of a treeline, without the manor in the background. The mast with the grey
sensor enclosure, the diagonal mast brace and the cabling from the body to the
mast are clearly readable. Under the body the equipment bay is open to view:
the light-green modules, the light-coloured mounting plate and the wiring
harness. The best photograph for showing the drive and equipment layout.

---

## `IMG20260810195217.jpg` — Close front view with mowing deck

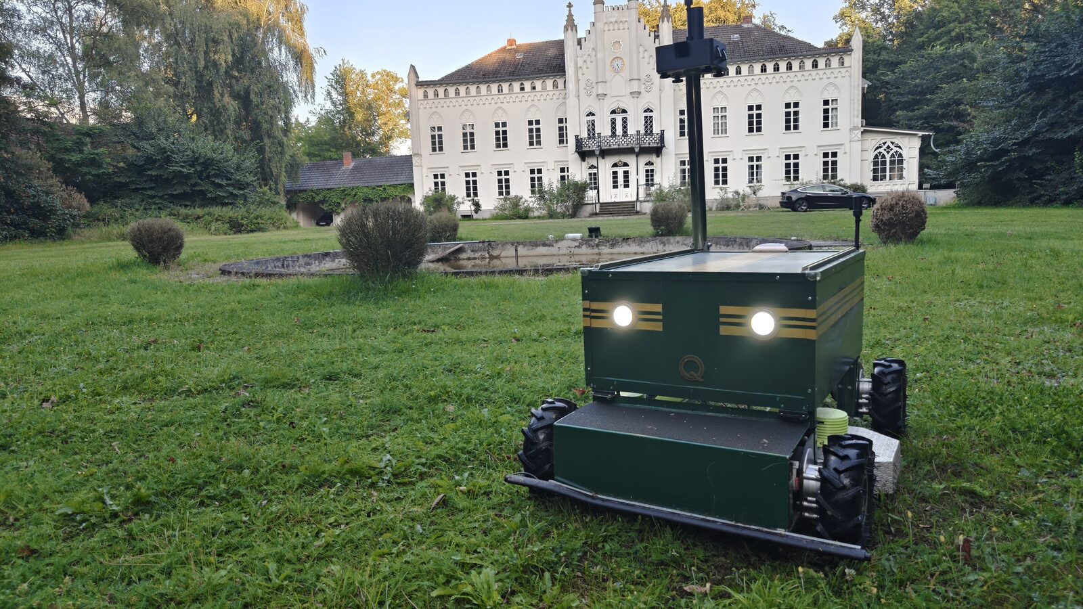
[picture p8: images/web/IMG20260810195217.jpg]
Close front view with the mowing deck


Front three-quarter view from close range at ground level. The front panel with
both lit headlights, the gold stripes and the `Q` marque fills the frame; ahead
of it the mowing deck with its front skid bar and the knobbly tyres of the
front axle. The mast and its sensor head rise out of the top edge of the frame.
The manor and the basin remain visible in the background. Suitable as an
alternative title image.

---

## Regenerating the web versions

The files in `web/` are generated from the originals with ImageMagick; the
command scales the long edge to 1600 px, drops all metadata (including the
camera's GPS tags) and writes progressive JPEGs at quality 82:

```bash
cd images && mkdir -p web
for f in *.jpg; do
  magick "$f" -auto-orient -resize "1600x1600>" -strip -interlace Plane -quality 82 "web/$f"
done
```

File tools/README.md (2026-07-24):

# 🛠️ Quassel UGV - CAN Communication Tools

Essential tools for testing and configuring the new CAN bus architecture.

## 📁 Directory Structure

```
tools/
└── README.md                      # This file
```

## 🚀 Quick Start

### Monitor CAN Traffic
```bash
# On Raspberry Pi
candump can0
```

### Send Test Messages
```bash
# On Raspberry Pi
cansend can0 123#DEADBEEF
```

### View CAN Interface Status
```bash
# On Raspberry Pi
ip link show can0
```

## 📋 Prerequisites

### Python Dependencies
```bash
pip install python-can
```

### Hardware Requirements
- Orange Pi Zero 2W with USB-CAN adapter for the sensor hub
- Main Raspberry Pi 3 with USB-CAN adapter (`gs_usb`)
- Former UGV test Raspberry Pi with USB-CAN adapter (offline)
- ODrive/ODESC controllers with integrated CAN interfaces
- CAN bus connection between Sensor Hub and Controller
- Proper CAN termination (120Ω resistors)
- Classical CAN 2.0 on every node; CAN FD is not used

## 🔧 CAN Architecture Overview

### Sensor Hub (Orange Pi Zero 2W)
- **Holybro UM982 RTK-GPS**: Dual-antenna for position and heading
- **WitMotion USB-IMU**: IMU with native orientation output
- **DSD TECH SH-C30A USB-CAN adapter (`gs_usb`)**: SocketCAN `can0`, Classical CAN 2.0 at 250 kbit/s
- **Sends**: GPS position, heading, RTK status, IMU orientation

### Controller (Pi 3)
- **Motor Controller**: Receives CAN messages from sensor hub
- **Web Interface**: Real-time Bing Maps display
- **USB-CAN adapter (`gs_usb`)**: SocketCAN `can0`, Classical CAN 2.0 at 250 kbit/s
- **Receives**: Sensor data from hub

### Former UGV Test Stand (Offline)
- **USB-CAN adapter**: SocketCAN `can0`, Classical CAN 2.0 at 250 kbit/s
- **ODrive/ODESC units**: Integrated CAN interfaces using SimpleCAN
- **Requirement**: Every test-bus node must be configured for 250 kbit/s

## 🔗 Integration Workflow

### 1. Test CAN Interface
```bash
# On Raspberry Pi
ip link show can0
candump can0
```

### 2. Monitor Sensor Data
```bash
# On Raspberry Pi - watch CAN messages
candump can0 -c
```

### 3. Verify Communication
- Check CAN messages are received
- Verify message format and content
- Confirm bidirectional communication between hub and controller

## 🐛 Troubleshooting

### Common Issues

#### "No module named 'python-can'"
```bash
pip install python-can
```

#### "CAN interface not found"
```bash
# On Raspberry Pi
ip link show can0

# Main UGV: verify USB-CAN driver and interface
lsusb
ip -details link show can0
```

All host computers use USB-CAN adapters. The main UGV and the Orange Pi
sensor hub use native `gs_usb`/SocketCAN; `slcand` is no longer part of the
productive CAN path.

#### "No CAN messages received"
- Verify CAN wiring (CANH, CANL, GND)
- Check 120Ω termination resistors
- Confirm the unified CAN bitrate of 250 kbit/s
- Ensure both devices have same bitrate

#### "CAN interface down"
```bash
# Main UGV production bus
sudo ip link set can0 up type can bitrate 250000 restart-ms 100

# UGV test stand (USB-CAN)
sudo ip link set can0 up type can bitrate 250000
```

## 📊 Expected Output

### Successful CAN Communication
```
Sensor Hub:
📡 GPS Position: 53.8234°N, 10.4567°E
🧭 Heading: 45.2° (Dual-Antenna)
📊 RTK Status: FIXED
📐 Roll: +2.3°, Pitch: -1.8°
🚀 CAN Message sent

Controller:
✅ Received sensor data from hub
📍 Position: 53.8234°N, 10.4567°E
🧭 Heading: 45.2°
📊 RTK: FIXED
```

### System Status Indicators
- 📡 GPS data received
- 🧭 Heading calculated
- 📊 RTK status displayed
- 📐 IMU orientation available
- 🚀 CAN messages transmitted

## 📞 Support

For issues with CAN communication:

1. **Check hardware connections** - CAN bus, power, USB
2. **Verify software dependencies** - Python packages installed
3. **Review CAN traffic** - Use candump to monitor messages
4. **Test individual components** - Use tools separately to isolate issues

## 🔄 Development

The new CAN architecture is designed for:
- ✅ **Modular design** - Separate sensor hub and controller
- ✅ **Real-time communication** - Continuous GPS/IMU CAN telemetry updates
- ✅ **Scalability** - Easy to add new sensors or controllers
- ✅ **Reliability** - Redundant communication paths

All components maintain compatibility with the Quassel UGV RTK-GPS + IMU system.

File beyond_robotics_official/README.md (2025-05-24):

# Arduino DroneCAN

This repository allows easy integration of sensors to be used with Ardupilot and PX4 via DroneCAN. Sensors can be integrated within minutes by using pre-existing Arduino libraries for sensors, and through this library which abstracts the DroneCAN layer so you can focus on sending and receiving messages.

By using the Arduino core and PlatformIO with pre-configured board setups, you can start developing instantly.

This isn't intended to be used in the same way as AP_Periph, which supports tons of sensors all at once and is highly adaptable without writing code. This is intended for writing a DroneCAN interface for any sensor or system, without having to deal with a large code base and lots of boilerplate.

## Features

API changes can happen at any time in master. See the releases page to download a specific verison for your project.

- Send DroneCAN messages ✅
- Receive DroneCAN messages ✅
- Send NodeStatus ✅
- Respond to NodeInfo ✅
- Reboot on reboot request ✅
- Dynamic Node Allocation ✅
- DroneCAN Parameters ✅
- Firmware update over CAN ✅

## Currently Supported Hardware

This repository is plug and play with the Beyond Robotix CAN node series!

See [Beyond Robotix Can Node](https://www.beyondrobotix.com/products/micro-can-node-development-bundle)

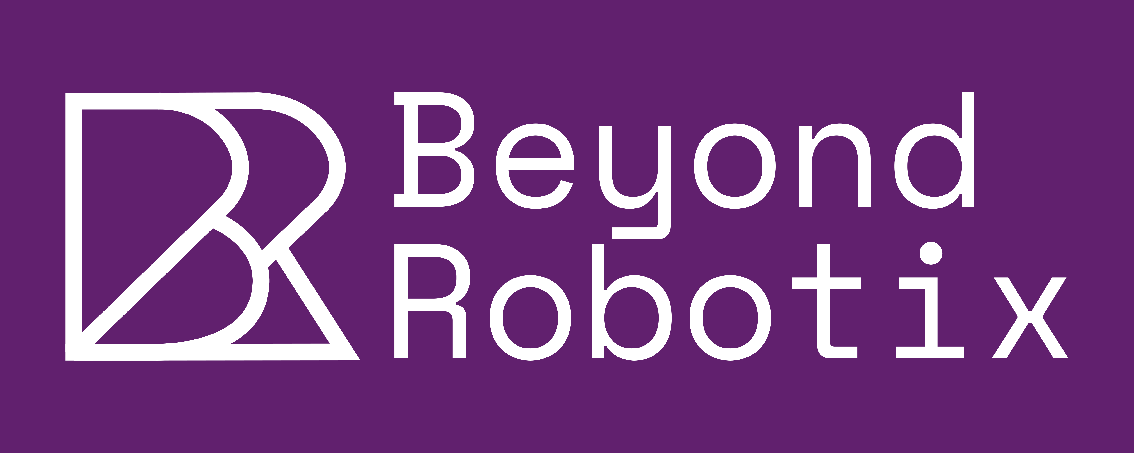
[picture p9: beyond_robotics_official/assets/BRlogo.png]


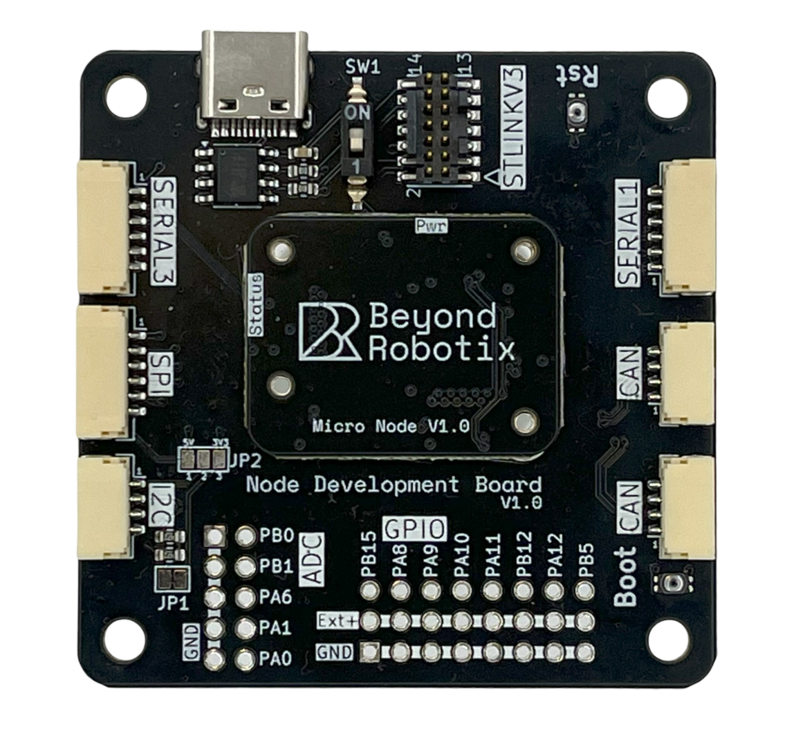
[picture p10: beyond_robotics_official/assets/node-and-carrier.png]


We've got some handy docs for the node hardware and some more software explaination and examples here [CAN node gitbook](https://beyond-robotix.gitbook.io/docs/can-node-system)

## Code Usage

See [Beyond Robotix Gitbooks ArduinoCAN documentation](https://beyond-robotix.gitbook.io/docs/can-node-system/arduino-dronecan) for more information!

## Support

If you get stuck with this repository, the discussions section will allow us to help out.

For dedicated engineering support on your application, contact [admin@beyondrobotix.com](admin@beyondrobotix.com). We can also quote for writing custom firmware for you!

## Repository structure

This repository is designed to be cloned and run straight away using the example application in ./src/main.cpp.

All 3 of the following libraries are required:

- ./lib/arduino_dronecan contains the library which has been written to make dronecan plug and play
- ./lib/dronecan contains the actual dronecan message types generated by dronecan_dsdlc
- ./lib/libcanard contains the canard library which handles parsing of dronecan messages

There is some platformio boilerplate to do to support new boards
- ./boards
- ./variants

The required repos to generate the dronecan messages etc are in ./dronecan, although ./lib already contains the generated files so these are just for reference.

## Standing on the shoulders of Giants.

This repo is built on many resources:
- Arduino Core https://github.com/stm32duino/Arduino_Core_STM32
- Basis of the CAN API https://github.com/nopnop2002/Arduino-STM32-CAN/blob/master/stm32l452/stm32l452.ino#L55
- How to use libcanard https://github.com/dronecan/libcanard/blob/master/examples/ServoNode/servo_node.c
- https://github.com/seeers/CAN-Bus-Arduino_Core_STM32/blob/master/CanLowlevel.ino
- https://github.com/geosmall/UAVCAN-for-STM32-Arduino/blob/master/libcanard_example/src/libcanard/drivers/stm32/canard_stm32.c
- the platformio board is based on this being the closest supported board https://docs.platformio.org/en/latest/boards/ststm32/nucleo_l432kc.html
- These are the HAL drivers for the specific MCU being used, although they're all generic https://github.com/stm32duino/Arduino_Core_STM32/tree/main/variants/STM32L4xx/L431C(B-C)(T-U)

Other stuff which didn't get used but interesting 
- https://github.com/UBC-Solar/firmware-v2/tree/master
- https://github.com/geosmall/UAVCAN-for-STM32-Arduino/blob/master/libcanard_example/src/libcanard/drivers/stm32/canard_stm32.c
- https://github.com/pazi88/8Ch-EGT
- https://github.com/J-f-Jensen/libraries/blob/master/STM32CAN/STM32CAN.cpp
- https://github.com/Dmivaka/STM32-HAL-Libcanard/tree/main

Other notes
- No CAN API support in STM32 Arduino https://github.com/stm32duino/Arduino_Core_STM32/issues/259
- The HAL drivers are generated for L431 but not working https://community.st.com/t5/stm32cubemx-mcus/the-stm32cubeide-does-not-generate-the-stm32h7xx-hal-driver-file/td-p/101970

## Dronecan DSDLC

If you want to generate the dronecan message headers from scratch, ensure you have the submodules cloned, then:

> cd dronecan

> python dronecan_dsdlc/dronecan_dsdlc.py -O ../lib/dronecan

[dronecan generate files](https://github.com/dronecan/dronecan_dsdlc)

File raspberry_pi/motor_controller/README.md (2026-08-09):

# Motor Controller v2.0

Modularer Motor Controller für Quassel UGV mit Hardware-PWM, ODrive-USB,
legacy CAN und Web-Interface.

## Aktuelle ODrive- und SensorHub-Anbindung

- Der Haupt-UGV-Rechner nutzt **zwei direkte USB/Fibre-Verbindungen** zu den
  beiden ODrive-Boards. Node 0/1 liegen auf Board A, Node 2 auf Board B.
- Die SensorHub-Pose kommt im Produktionsprofil per HTTP/WiFi.
- Der Client nutzt zwei parallele persistente NDJSON-Streams; der konfigurierte
  Basis-Endpunkt `/api/telemetry` wird intern zu `/api/telemetry/stream` erweitert.
- Der CAN-Dienst des Haupt-UGV ist deaktiviert; der CAN-Code bleibt nur fuer
  Legacy-/Testprofile erhalten und ist kein automatischer Rueckfall.
- Der ehemalige, inzwischen offline geschaltete UGV-Teststand nutzt einen **USB-CAN-Adapter** als `can0`.
- Die ODrive/ODESC-Motorcontroller besitzen jeweils eine **integrierte CAN-Schnittstelle** und sprechen SimpleCAN.
- Alle Teilnehmer verwenden **Classical CAN 2.0** mit maximal 8 Datenbytes pro Frame; CAN FD wird nicht verwendet.
- Legacy-CAN-Profile verwenden einheitlich **250 kbit/s**.
- `odrive_mower.transport` ist in Produktion `usb`; `can` ist nur ein explizites Legacy-/Testprofil.

## 🚀 Quick Start

### Installation
```bash
# Dependencies installieren
pip3 install -r requirements.txt

# pigpiod starten
sudo systemctl start pigpiod

# Config erstellen
cp config.yaml.example config.yaml
nano config.yaml
```

### Ausführen
```bash
# Mit Config-Datei
python3 -m motor_controller.main --config config.yaml

# Mit CLI-Args (Legacy)
python3 -m motor_controller.main --pwm --pins 18,19 --web --can can0
```

### Als Service
```bash
# Service installieren
sudo cp ../motor_controller_v2.service /etc/systemd/system/
sudo systemctl daemon-reload
sudo systemctl enable motor-controller-v2.service
sudo systemctl start motor-controller-v2.service

# Status prüfen
sudo systemctl status motor-controller-v2.service

# Logs anzeigen
sudo journalctl -u motor-controller-v2.service -f
```

## 📁 Struktur

```
motor_controller/
├── main.py                  # Entry Point
├── config.py                # Konfiguration
├── hardware/                # Hardware-Layer
│   ├── gpio_controller.py   # GPIO Singleton
│   ├── pwm_controller.py    # PWM (Motoren + Mäher)
│   └── safety_monitor.py    # Watchdog
├── communication/           # HTTP/WiFi- und Legacy-CAN-Transporte
│   ├── can_handler.py
│   └── can_protocol.py
├── control/                 # Steuerungs-Layer
│   ├── motor_control.py
│   └── joystick_handler.py
└── web/                     # Web-Layer
    └── web_server.py
```

## ⚙️ Konfiguration

Alle Parameter sind in `config.yaml` konfigurierbar:

```yaml
pwm:
  enabled: true
  pins:
    left: 19
    right: 18

web:
  enabled: true
  port: 80

can:
  interface: can0
  bitrate: 250000

sensor_hub:
  transport: wifi
  wifi_url: http://schloss.fdog.de:8081/api/telemetry
  auth_username: ugv          # Passwort: SENSOR_HUB_TELEMETRY_PASSWORD
  poll_interval_s: 0.2
  request_timeout_s: 1.5
  pause_timeout_s: 1.0
  telemetry_timeout_s: 30.0

web:
  enabled: true
  auth_enabled: true          # Passwort: UGV_WEB_PASSWORD
  auth_username: ugv

logging:
  level: INFO
  console: true
```

Die Weboberfläche und der SensorHub sind aus dem Internet erreichbar und
verlangen eine Anmeldung. Passwörter stehen in der Dienst-Umgebung, nicht in
dieser Datei - siehe [WEB_ZUGANGSSCHUTZ.md](../WEB_ZUGANGSSCHUTZ.md).

## 🔌 API

### REST Endpoints

- `GET /` - Web-Interface
- `GET /api/status` - System-Status
- `POST /api/can/toggle` - CAN Ein/Aus
- `POST /api/light/toggle` - Licht Ein/Aus
- `POST /api/mower/toggle` - Maehdeck nur mit explizitem JSON-Zustand
  (`{"state": true, "rpm": 500}` oder `{"state": false}`); fehlendes,
  unlesbares oder nicht-boolesches `state` wird mit HTTP 400 abgelehnt
- `POST /api/mower/speed` - Mäher-Geschwindigkeit
- `POST /api/joystick` - Joystick-Input
- `GET /api/sensor/status` - Sensor-Status anfordern
- `POST /api/sensor/restart` - Sensor Hub neu starten
- `POST /api/mapping/maps/<name>/plan/simulate` - einen Plan ohne Hardware mit
  dem produktiven Navigationscontroller und einem kinematischen Fahrzeugmodell
  simulieren
- `POST /api/notifications/test` - Testmeldung an das konfigurierte ntfy-Topic

## 📲 Push-Meldungen bei Störungen

Bleibt das Fahrzeug wegen eines Fehlers stehen, färbt die Oberfläche den
Zustand rot - das hilft aber nur, solange jemand hinsieht. Optional geht
dieselbe Information als Push-Nachricht aufs Telefon.

### Einrichten

1. Auf dem Telefon die **ntfy**-App installieren (Android/iOS).
2. Einen zufälligen Topic-Namen wählen. Bei `ntfy.sh` darf jeder mitlesen und
   mitschreiben, der den Namen kennt - er ist damit ein Passwort. Zum Beispiel:

   ```bash
   head -c 18 /dev/urandom | base64 | tr -d '/+=' 
   ```

3. Denselben Namen in der App abonnieren und auf dem Fahrzeug in
   `/etc/ugv-web.env` eintragen:

   ```
   UGV_NTFY_TOPIC=<der gewählte Name>
   ```

4. In `config.yaml` unter `notifications:` `enabled: true` setzen, Dienst neu
   starten und die Kette prüfen:

   ```bash
   curl -u ugv:PASSWORT -X POST http://<ugv>/api/notifications/test
   ```

Für ein eigenes oder zugangsgeschütztes ntfy zusätzlich `UGV_NTFY_SERVER` und
`UGV_NTFY_TOKEN` setzen.

### Was gemeldet wird

- **Sicherheitsstopp** (`SafetyMonitor`): Sicherheitsschaltleiste, CAN-Ausfall,
  ODrive-Fehler, SensorHub-Timeout - mit der tatsächlichen Ursache.
- **Fahrpause**, die länger als `motion_hold_after_s` anhält. Kurze
  Telemetrielücken lösen sich in Sekunden und bleiben still.
- **Abbruch einer Planfahrt**: `mower_fault`, `nogo_stop`, `rtk_lost`,
  `heading_block`, `track_stall`, `geofence`, Navigations-Watchdog und jeder
  weitere Zustand, der nicht ausdrücklich als gewollt gilt. Bewusst pausierte,
  gestoppte oder fertige Pläne lösen nichts aus.
- **Dienst-Neustart** mit offenem Wiederaufsetzpunkt - der Fall, in dem das
  System nach einem Absturz sonst stumm dasteht.
- **Entwarnung**, wenn die Fahrt weitergeht, der Plan fertig wird oder ein
  Sicherheitsstopp entriegelt wird (`notify_recovery: false` schaltet das ab).

### Eigenschaften

Gemeldet wird die Flanke, nicht der Zustand: derselbe Fehler kommt einmal, nicht
im Sekundentakt. Das Senden läuft in einem eigenen Thread mit Warteschlange und
Wiederholversuchen bis `retry_max_age_s` - ein Fahrzeug, das gerade wegen einer
schlechten Funkverbindung stehenbleibt, meldet sich also nach, sobald das Netz
wieder da ist. Jede Meldung trägt die Uhrzeit des Ereignisses im Text. Fehler
des Meldewegs bleiben im Journal und erreichen nie die Steuer- oder
Sicherheitsthreads.

## Offline-Fahrtsimulation

Die Kartenansicht bietet fuer jeden berechneten oder geladenen Plan
`Fahrt simulieren`. Die Simulation arbeitet auf den tatsaechlich ausfuehrbaren
Segmenten nach Startpunktauswahl, Ringrotation und Uebergangsrouting. Sie nutzt
den produktiven `NavigationController`; nur Motoren und Posequelle werden durch
ein einfaches Skid-Steer-Modell ersetzt.

Das Ergebnis enthaelt und visualisiert:

- simulierte Fahrspur fuer Vorwaerts-, Rueckwaerts- und Uebergangssegmente,
- Fahrzeug-Footprint an der End- oder Stopposition,
- Segmentzustand, Fahrzeit und tatsaechliche Strecke,
- No-Go-Warnungen und denselben Footprint-Stopp wie bei der realen Ausfuehrung.

Das Modell ist keine Gras-/Reifen-Physiksimulation. Es dient als reproduzierbare
Vorpruefung fuer Segmentreihenfolge, Uebergaenge, Startposition, Controller-
Verhalten und Sicherheitsabstaende. Feldtests bleiben fuer Traktion, Schlupf,
Nachlauf und reale Motorreaktion erforderlich.

### Geplante Coverage-Optimierung

Schmale Restkeile, in die keine mindestens 2 m lange reine Restbahn passt,
bleiben derzeit unbefahren. Eine kuenftige Planerstrategie darf solche Bahnen
in bereits durch Konturfahrten gemaehte Innenbereiche verlaengern. Der doppelt
gemaehte Anteil ist dabei ein erlaubter Verbindungskorridor und macht die
eigentliche Restbahn lang genug fuer eine stabile Vor-/Rueckwaertsfahrt. Diese
Strategie soll optional bleiben und im Simulator anhand von Restflaeche,
Doppelmaehstrecke, Wendungen und Sicherheitsabstand verglichen werden.

## 🔧 Features

- ✅ Hardware-PWM (GPIO 18/19) via pigpio
- ✅ Mäher-Steuerung (Relay + PWM)
- ✅ Licht-Steuerung (Relay)
- ✅ Sicherheitsschalter (Emergency Stop)
- ✅ Timeout-Watchdog
- ✅ Ramping-System
- ✅ CAN-Bus JSON-Kommunikation
- ✅ Web-Interface mit Joystick
- ✅ Thread-Safe
- ✅ Strukturiertes Logging

## 📝 Logging

```bash
# Console-Logs (wenn console: true)
2024-11-04 12:00:00 - motor_controller.main - INFO - ✅ Alle Komponenten initialisiert

# Systemd-Journal
sudo journalctl -u motor-controller-v2.service -f

# Log-Level ändern (in config.yaml)
logging:
  level: DEBUG  # DEBUG, INFO, WARNING, ERROR, CRITICAL
```

## 🛠️ Troubleshooting

### pigpio nicht erreichbar
```bash
sudo systemctl start pigpiod
sudo systemctl enable pigpiod
```

### CAN-Interface nicht verfügbar
```bash
# Nur fuer Legacy/Testprofile mit USB-CAN, Classical CAN 2.0
sudo ip link set can0 up type can bitrate 250000 restart-ms 100
```

Am UGV-Teststand wird stattdessen der USB-CAN-Adapter über
`ugvtestpi-usbcan0.service` mit 250 kbit/s aktiviert.

### Port 80 bereits belegt
```yaml
# In config.yaml anderen Port verwenden
web:
  port: 8080
```

### Import-Fehler
```bash
# PYTHONPATH setzen
export PYTHONPATH=/home/nicolay:$PYTHONPATH
```

## 🔒 Sicherheit

- Optionaler Sicherheitsschalter (GPIO 17, `safety.enabled` in config.yaml) stoppt und
  verriegelt Fahrantrieb und Mähdeck, sofern verbaut. Am UGV auf raspberrycan ist
  kein Schalter vorhanden; dort ist `safety.enabled: false` gesetzt.
- Command-Timeout (2s) stoppt Motoren bei fehlenden Befehlen
- Joystick-Timeout (1s) stoppt Motoren bei Verbindungsabbruch
- Nach 1 s ohne SensorHub-Pose pausiert der Watchdog nur Fahrantrieb und Route;
  das Maehdeck darf weiterlaufen. Nach Rueckkehr einer frischen Pose wird eine
  zuvor aktive autonome Route automatisch am Resume-Punkt fortgesetzt.
- Erst nach 10 s ohne SensorHub-Pose oder sofort bei fehlender ODrive-USB-Achse
  verriegelt der Watchdog den Gesamtsystem-Stopp inklusive Maehdeck.
- Native USB-Telemetrie überwacht alle drei Mähmotorströme mit konfigurierbaren Zeitgrenzen.
- Der USB-Monitor liest im IDLE alle 100 ms und fuettert den lokalen Watchdog. Dadurch
  bleibt der lokale 1,0-s-ODrive-Watchdog gefüttert; bei Pi-/Kabelausfall läuft
  er ab und disarmt die Achse lokal.
- Der verriegelte Stopp wird in der Web-Oberfläche angezeigt und kann dort erst
  nach wiederhergestellten USB-Verbindungen manuell zurückgesetzt werden.

Die ODrive-Watchdogs sind auf den drei genutzten Achsen mit 1,0 s gespeichert.
Fuer eine erneute Einrichtung muss der Motor-Controller-Dienst gestoppt sein:

```bash
# Board A (Nodes 0 und 1)
python3 scripts/configure_odrive_watchdog.py apply --serial 0x386132523135 --nodes 0,1 --timeout 1.0

# Board B (nur verwendeter Node 2; Node 3 bleibt unverändert)
python3 scripts/configure_odrive_watchdog.py apply --serial 0x387132523135 --nodes 2 --timeout 1.0
```

## 📊 GPIO-Belegung

| GPIO | Funktion |
|---|---|
| 18 | Motor rechts (PWM) |
| 19 | Motor links (PWM) |
| 22 | Licht (Relay) |
| 23 | Mäher (Relay) |
| 12 | Mäher (PWM) |
| 17 | Sicherheitsschalter (optional, an raspberrycan nicht verbaut) |

## 🌐 Web-Interface

```bash
# Zugriff über Browser
http://raspberrycan/

# API-Status
curl http://raspberrycan/api/status
```

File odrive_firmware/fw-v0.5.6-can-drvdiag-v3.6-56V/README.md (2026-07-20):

# ODrive v3.6-56V CAN DRV diagnostics firmware

Build target: ODrive v3.6-56V

Upstream source: `odriverobotics/ODrive` tag `fw-v0.5.6`

Upstream commit: `a308314ed2ca613164b81e7bbdfacc53cd1859ff`

Compiler: `arm-none-eabi-gcc 10.3.1`

Build configuration: debug off, doctest off, LTO off

The firmware adds CANSimple command `0x1e` (`MSG_GET_DRV_FAULT`). Send an RTR
frame to `(node_id << 5) | 0x1e`. The eight-byte response contains:

- bytes 0-3: `uint32` `axis.last_drv_fault`, little-endian
- bytes 4-7: `float32` FET temperature in degrees Celsius, little-endian

Examples for nodes 0 and 1:

```sh
cansend can0 01E#R
cansend can0 03E#R
```

For compatibility with the existing mower controller, requested axis state `5`
is accepted as an alias for closed-loop control. Sensorless operation still
requires `axis.config.enable_sensorless_mode = true`. The heartbeat continues
to report state `5`, so the existing mixed old/new ODrive installation remains
compatible.

Artifact SHA-256:

- HEX: `90362d3863c946b7d0510f20769194b3473752c02e3df281f4a221550f6394bd`
- ELF: `596c108401ba842f971a99e4b8ab121149eb54bed2e8d8281ac9b5d0caadb226`
- BIN: `91d13ebb8e8ac1dbd6120e6572308c2bf1f43faf44d18f00a76ad0f863fcd5e4`

The pre-flash configuration backup for board serial `0x386132523135` is in
`odrive_backups/odrive-node0-1-before-diag-20260720.json`.

## UGV Board A deployment

Flashed and read-back verified on 2026-07-20 on Board A, USB serial
`0x386132523135`. The controlled migration is in
`migrate_board_a_config.py`; `flash_board_a_known_hw.py` documents the required
DFU fallback for this early v3.6 board, whose hardware-version OTP field is not
readable in STM32 DFU mode.

Important migration detail: fw-v0.5.6 represents CANSimple as the bit flag
`PROTOCOL_SIMPLE = 1`. The legacy configuration used protocol value `0`; using
that old value on 0.5.6 leaves CAN electrically enabled but sends no CANSimple
heartbeats or responses.

Post-deployment checks:

- CAN 2.0 at 250 kbit/s
- node IDs 0 and 1, 100 ms heartbeats
- both axes IDLE, no startup movement enabled
- sensorless mode enabled; requested state 5 compatibility patch active
- command `0x1e` returns `last_drv_fault = 0` on both axes

The migration now also enables the 1.0 s axis watchdog. This is intentionally
paired with the Raspberry Pi's continuous 100 ms `GET_IQ` polling: every
CANSimple request feeds the watchdog, while a host or cable failure makes the
axis disarm locally. Boards configured before this change must receive the
one-time USB watchdog update before autonomous mower operation.

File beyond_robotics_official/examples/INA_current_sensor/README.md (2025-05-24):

# INA current sensor example

This example illustrates how an already availible library can be used to easily integrate a new sensor into dronecan.

**this is untested code currently** I'll be able to test it at some point when I get an INA to hand.

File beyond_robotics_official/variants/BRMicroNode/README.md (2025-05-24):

# BR Micro Node Variant

This project contains the files required for platformio to work for the Beyond Robotix Micro CAN node !

See https://github.com/BeyondRobotix/Arduino-DroneCAN

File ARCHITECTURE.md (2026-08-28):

# Quassel UGV - Skalierbare Architektur

Der verbindliche aktuelle Hardware- und Transportstand steht in
[`CURRENT_PRODUCTION.md`](CURRENT_PRODUCTION.md).

## 🎯 Vision
Modulare, erweiterbare Plattform für autonome Rasenmäher mit:
- Waypoint-Navigation & Pfadplanung
- Flächenberechnung & Mähbereichsverwaltung
- Echtzeit-Telemetrie & Monitoring
- Sicherheitssysteme & Notfallbehandlung
- Web-Interface & Remote-Steuerung

## Verbindlicher Produktionsstand

Alles haengt direkt am Raspberry Pi: der GNSS-Empfaenger ueber eine serielle
USB-Verbindung, die beiden ODrive-v3.x-Boards ueber zwei USB/Fibre-Leitungen.
Die drei verwendeten Maehachsen werden ueber USB-Seriennummer und Achsindex
eindeutig zugeordnet.

CAN-Bus und SensorHub sind ausgebaut, ihr Code ist aus dem Repository entfernt.
Sie duerfen nicht wieder als Produktionsabhaengigkeit eingefuehrt werden.

| Einsatz | Aktiver Transport | Profil |
|---|---|---|
| GNSS-Empfaenger UM982 → Raspberry | serielle USB-Verbindung | Port ueber `/dev/serial/by-id` |
| RTK-Korrekturen → Raspberry | NTRIP ueber Mobilfunk | Mountpoint `openrtk_mv` |
| Raspberry → ODrive Board A/B | zwei direkte USB/Fibre-Leitungen | Seriennummer + Axis 0/1 |

Die Pose entsteht damit auf dem Fahrzeugrechner selbst. Bleibt sie aus,
pausiert der System-Watchdog nach einer kurzen Frist nur Fahrantrieb und
Route. Erst nach der langen Ausfallfrist verriegelt er den Gesamtstopp
inklusive Maehdeck. Nach Rueckkehr der Pose wird eine zuvor aktive autonome
Route automatisch am gespeicherten Resume-Punkt fortgesetzt.

## 📁 Projektstruktur

```
raspberry_pi/
├── config/
│   ├── __init__.py
│   ├── settings.py          # Zentrale Konfiguration
│   └── constants.py         # Alle Konstanten (GPIO, PWM, Raten)
│
├── core/
│   ├── __init__.py
│   ├── motor_controller.py  # Orchestrator (vereinfacht)
│   ├── gpio_manager.py      # GPIO-Abstraktion
│   └── pose_cache.py        # Zwischenspeicher der GNSS-Pose
│
├── subsystems/
│   ├── __init__.py
│   ├── pwm_controller.py    # Motor-PWM mit Ramping
│   ├── light_controller.py  # Licht-Relais
│   ├── mower_controller.py  # Mäher-Steuerung
│   └── safety_controller.py # Sicherheitsschalter
│
├── navigation/              # 🚀 Für zukünftige Erweiterung
│   ├── __init__.py
│   ├── waypoint_planner.py  # Waypoint-Navigation
│   ├── path_optimizer.py    # Pfad-Optimierung
│   └── area_calculator.py   # Flächenberechnung
│
├── web/
│   ├── __init__.py
│   ├── app.py               # Flask-App
│   ├── routes.py            # API-Routes
│   ├── websocket_handler.py # WebSocket für Joystick
│   └── templates/
│       └── index.html
│
├── utils/
│   ├── __init__.py
│   ├── logger.py            # Logging-System
│   └── exceptions.py        # Custom Exceptions
│
└── motor_controller.py      # Entry Point (vereinfacht)
```

## 🔄 Datenfluss

```
Web-Interface (Joystick/API)
    ↓
MotorController (Orchestrator)
    ├→ PWMController (Motor-Steuerung)
    ├→ LightController (Licht)
    ├→ MowerController (Mäher)
    ├→ SafetyController (Sicherheit)
    └→ PoseCache ← LocalPoseSource (GNSS über USB)
         ↓
    Pose zurück
```

## 🛡️ Sicherheitskonzept

1. **Hierarchische Kontrolle**
   - Safety-Pin hat höchste Priorität
   - Eine veraltete Pose pausiert Fahrantrieb und Route
   - Manuelles Rangieren bleibt erlaubt, es braucht keine Pose

2. **Timeout-Mechanismen**
   - Joystick-Timeout: 1.0s
   - Command-Timeout: 2.0s
   - Automatischer Notaus bei Timeout

3. **State-Management**
   - Klare Zustände (IDLE, MANUAL, AUTONOMOUS, EMERGENCY)
   - Zustandsübergänge validiert

## 🚀 Zukünftige Module

### Navigation (Phase 2)
- Waypoint-Planung mit GPS
- Pfad-Optimierung (Dijkstra/A*)
- Flächenberechnung & Mähbereichsverwaltung
- RTK-GPS Integration (NTRIP am Raspberry)

### Autonomie (Phase 3)
- Autonome Mährouten
- Hindernis-Vermeidung
- Rückkehr zur Basis
- Batterie-Management

### Monitoring (Phase 4)
- Telemetrie-Dashboard
- Fehlerbehandlung & Logging
- Performance-Metriken
- Remote-Diagnostik

## 💾 Konfiguration

Alle Einstellungen in `config/settings.py`:
```python
# GPIO-Pins
GPIO_PWM_LEFT = 19
GPIO_PWM_RIGHT = 18
GPIO_LIGHT = 22
GPIO_SAFETY = 17

# PWM-Parameter
PWM_FREQUENCY = 50  # Hz
PWM_NEUTRAL = 1500  # μs
PWM_MIN = 1000
PWM_MAX = 2000

# Ramping-Raten
ACCELERATION_RATE = 25      # μs/s
DECELERATION_RATE = 800     # μs/s
BRAKE_RATE = 1500           # μs/s

# Mähdeck: läuft über die ODrives (odrive_mower), nicht über GPIO-PWM

# Timeouts
JOYSTICK_TIMEOUT = 1.0
COMMAND_TIMEOUT = 2.0
SAFETY_DEBOUNCE = 0.5
```

## 🔌 API-Struktur

```
GET  /api/status              # System-Status
POST /api/joystick            # Joystick-Input
POST /api/light/toggle        # Licht an/aus
POST /api/mower/toggle        # Mäher an/aus
POST /api/mower/speed         # Mäher-Geschwindigkeit
GET  /api/sensor/status       # Pose samt Alter
```

## 📊 Implementierungs-Reihenfolge

1. ✅ Config-System
2. ✅ GPIO-Manager
3. ✅ Subsystem-Klassen
4. ✅ PWM-Controller
5. ✅ Pose-Zwischenspeicher
6. ✅ Web-Interface
7. ✅ Hauptklasse vereinfachen
8. 🚀 Navigation-Module (später)

---

**Status**: Architektur-Plan erstellt | **Nächster Schritt**: Config-System implementieren

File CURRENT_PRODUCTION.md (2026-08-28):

# Quassel UGV – verbindlicher Produktionsstand

Stand: 24.07.2026

Diese Datei ist die maßgebliche Transport- und Hardwareübersicht für neue
Arbeiten am UGV. CAN-Bus und SensorHub sind ausgebaut; ihr Code wurde aus dem
Repository entfernt.

## Produktive Verbindungen

| Verbindung | Aktiver Transport |
|---|---|
| GNSS-Empfänger UM982 → Raspberry-Hauptrechner | serielle USB-Verbindung, Port über `/dev/serial/by-id` |
| Raspberry → ODrive Board A | direkte USB/Fibre-Verbindung, Serial `386132523135`, Axis 0/1 = Node 0/1 |
| Raspberry → ODrive Board B | direkte USB/Fibre-Verbindung, Serial `387132523135`, Axis 0 = Node 2 |
| Raspberry → Fahrmotorcontroller | Hardware-PWM über GPIO 19/18 |

Die Pose entsteht auf dem Raspberry selbst: Der Empfänger liefert NMEA über
USB, die RTK-Korrekturen holt der Raspberry per NTRIP. Es gibt keinen zweiten
Rechner mehr, dessen Ausfall die Navigation pausieren könnte.

## Zugangsschutz der Weboberflächen

Die Steuerungsoberfläche ist über eine Portfreigabe aus dem Internet
erreichbar: extern `8080` → `raspberrycan:80`. Die Ports 80 und 443 zeigen auf
ein anderes Gerät im Netz, nicht auf das UGV.

Sie verlangt eine Anmeldung per HTTP-Basic-Auth; das Passwort steht in
`/etc/ugv-web.env` (Modus 600), nie in der Konfigurationsdatei. Ohne gesetztes
Passwort antwortet sie mit 503 statt ungeschützt zu laufen.

Die Verbindung ist unverschlüsselt; das Passwort ist unterwegs mitlesbar.
Einzelheiten und die Nachrüstung von TLS: `raspberry_pi/WEB_ZUGANGSSCHUTZ.md`.

## Fernzugriff über den Rückwärtstunnel

Die SIM-Karte des Fahrzeugs hat keine öffentliche IP – Mobilfunk liegt hinter
Carrier-Grade-NAT, eingehende Verbindungen sind damit unmöglich. Der Weg dreht
sich deshalb um: Das Fahrzeug baut die Verbindung **hinaus** zur Synology im
Schloss auf und hält sie offen (`raspberry_pi/ugv-reverse-tunnel.service`,
Ziel in `/etc/ugv-tunnel.env`, Vorlage `raspberry_pi/ugv-tunnel.env.example`).

| Auf der Synology | führt zu |
|---|---|
| `127.0.0.1:18080` | Weboberfläche des Fahrzeugs, Port 80 |
| `127.0.0.1:12222` | SSH des Fahrzeugs, Port 22 |

Beide Enden binden auf `127.0.0.1`; was nach außen soll, veröffentlicht dort
der DSM-Reverse-Proxy gezielt per HTTPS. Der SSH-Kanal ist kein Beiwerk: Sobald
das Fahrzeug am Mobilfunkrouter hängt, ist die SSH-Portfreigabe der FRITZ!Box
auf das Fahrzeug tot, und ohne diesen zweiten Kanal bliebe für die Wartung nur
die Weboberfläche. Wartungszugang von außen:

    ssh -J ugvtunnel@schloss.fdog.de:2224 -p 12222 nicolay@127.0.0.1

**DSM erlaubt Portweiterleitung nicht von sich aus.** Der ausgelieferte
`sshd_config` setzt `AllowTcpForwarding no` und macht nur für `root` und
`admin` eine Ausnahme; ohne einen eigenen `Match User`-Block scheitert der
Tunnel mit `remote port forwarding failed`. Der Block wird über eine Aufgabe im
DSM-Aufgabenplaner nach jedem Neustart wiederhergestellt, weil ein DSM-Update
die Datei ersetzen kann. Nach größeren DSM-Updates gehört deshalb geprüft, ob
der Tunnel noch steht.

## Datenverbrauch der Weboberfläche

Das Fahrzeug hängt an einer SIM-Karte, deshalb ist der Statusstrom zur
Oberfläche auf Sparsamkeit ausgelegt:

- Der Server schiebt nur die **Änderung** gegenüber der letzten Sendung
  (`status_delta`); den vollen Stand (`status_update`) bekommt nur, wer sich
  gerade verbunden hat oder eine Differenz verpasst hat. Statt gut 5,5 kB
  gehen im Mittel rund 0,7 kB über die Leitung.
- Gesendet wird nur, solange mindestens eine Oberfläche offen ist. Steht das
  Fahrzeug, einmal je Sekunde; sobald es fährt, mäht, aufzeichnet oder
  gestört ist, viermal (`web.status_interval_idle_s`/`_active_s`).
- Zahlen werden vorher auf die angezeigte Genauigkeit gerundet, Alterswerte
  auf ganze Sekunden. Sonst bestünde die Differenz nur aus Rauschen.
- Der Browser hält keinen zweiten Abrufkanal mehr offen; `/api/status` bleibt
  für Diagnose per curl und liefert dort die ungerundeten Werte.
- Der Joystick sendet nur bei geänderter Auslenkung, dazu alle 200 ms ein
  Lebenszeichen für den Fahr-Wachhund.
- Socket.IO verbindet direkt per WebSocket; die HTTP-Polling-Phase entfällt.
  Lässt ein Netz keinen WebSocket durch, fällt der Browser von selbst zurück.
- Textantworten gehen gzip-komprimiert raus, die Oberfläche trägt ein ETag –
  ein erneuter Aufruf kostet dann nichts mehr statt 90 kB.

## CAN-Status

- Ausgebaut. Kein CAN-Adapter, kein CAN HAT, kein Device-Tree-Overlay, kein
  `can0`, keine `can-interface.service`.
- Der zugehörige Code ist aus dem Repository entfernt: CAN-Handler, CAN-
  Protokoll, die Testskripte und das SensorHub-Verzeichnis.
- Die ODrives hängen ausschließlich an ihren USB/Fibre-Leitungen.
- Eine mitgereiste alte `config.yaml` startet weiter: die Abschnitte `can` und
  `sensor_hub` werden mit einer Warnung im Journal übernommen bzw. verworfen.
  Der Abschnitt heißt jetzt `pose`.

## Safety

- Nach etwa 1 s ohne aktuelle GNSS-Pose pausieren Fahrantrieb und Route.
- Kehrt die Pose zurück, wird eine aktive Route aus der Speicherpause exakt
  fortgesetzt.
- Nach längerem Ausfall verriegelt der Gesamtsystem-Stopp einschließlich
  Mähdeck.
- Alle drei Mähachsen besitzen einen lokalen ODrive-Watchdog und werden über
  USB auf Zustand, Strom, Drehzahl und Fehler überwacht.
- Diese Überwachung läuft im zentralen Safety-Watchdog, nicht im Mähdeck-Thread.
  Ein libfibre-Aufruf blockiert seinen Thread ohne Timeout; eine Prüfung, die
  im selben Thread lebt, fällt mit ihm aus. Läuft das Deck, führen hängender
  Transport, veralteter Status, ODrive-Fehler, verlassener Closed-Loop und ein
  stehendes Messer zum Gesamtstopp. Ein hängender USB-Aufruf beendet danach den
  Prozess (Exit 70), weil er prozessintern nicht abbrechbar ist; systemd startet
  neu, die Messer sind zu diesem Zeitpunkt bereits vom ODrive-Watchdog entwaffnet.

## Vorgabe für weitere Entwicklung

Navigation, Pfadplanung, Weboberfläche und Mählogik müssen auf dieser
USB-Architektur weiterentwickelt werden. CAN darf dabei nicht wieder als
Produktionsabhängigkeit eingeführt werden.

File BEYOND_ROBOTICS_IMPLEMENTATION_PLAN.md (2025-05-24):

# Beyond Robotics Implementation Plan
## Based on Official Support Response

### PROBLEM ANALYSIS
The Beyond Robotics support team identified that our custom PlatformIO configuration may not have Serial2 configured correctly for the STM32L431 Micro Node. They provided a comprehensive solution using their official Arduino-DroneCAN repository.

### SOLUTION OVERVIEW
1. **Root Cause**: Custom configuration lacks proper Serial2 setup
2. **Official Solution**: Use pre-configured Arduino-DroneCAN v1.2 project
3. **Process**: Flash AP bootloader → Use official project → Customize for application
4. **Benefits**: Working serial communication + DroneCAN functionality

---

## IMPLEMENTATION STEPS

### Phase 1: Download Required Files
**Files to Download from GitHub Release v1.2:**
- `ArduinoDroneCAN.V1.2.zip` - Official project with proper configuration
- `AP_Bootloader.bin` - Bootloader for firmware updates over CAN
- STM32CubeProgrammer - For flashing bootloader

**Download URLs:**
- Release page: https://github.com/BeyondRobotix/Arduino-DroneCAN/releases/tag/v1.2
- STM32CubeProgrammer: https://www.st.com/en/development-tools/stm32cubeprog.html

### Phase 2: Flash AP Bootloader
```bash
# Using STM32CubeProgrammer
# Flash AP_Bootloader.bin to start address 0x8000000
# Node will boot in maintenance mode on CAN bus
```

**Hardware Setup:**
- SW1 in position "1" (STLINK enabled)
- ST-LINK V3 connected to STLINK header
- Use provided cable between ST-LINK and dev board

### Phase 3: Setup Official Project
1. Extract `ArduinoDroneCAN.V1.2.zip`
2. Open project in VSCode with PlatformIO
3. Press upload to flash firmware
4. Verify serial output on COM8
5. Confirm CAN message transmission

### Phase 4: Verify Functionality
**Expected Results:**
- Serial traffic on COM8 at 115200 baud
- Battery messages visible in CAN monitor
- Node appears on CAN bus properly

### Phase 5: Customize for Application
- Modify `src/main.cpp` for DroneCAN communication with Orange Cube
- Integrate with existing Orange Cube configuration
- Test end-to-end communication

---

## SUPPORT RESPONSE KEY POINTS

### Hardware Verification
✅ **Confirmed Correct:**
- SW1 in position "1" for STLINK
- Hardware connections verified

❓ **Question from Support:**
- Are you using the provided cable between ST-LINK and dev board?

### Software Issues Identified
❌ **Problem:** Custom PlatformIO configuration
- Serial2 not configured correctly
- Missing proper board setup

✅ **Solution:** Official repository
- Everything pre-configured for Arduino and DroneCAN
- Proper PlatformIO setup included
- Working library for DroneCAN integration

### Additional Features
- **AP Bootloader**: Enables firmware updates over CAN
- **Maintenance Mode**: Node shows on CAN bus during boot
- **Debugging Support**: Breakpoint debugging available if needed

---

## NEXT STEPS

1. **Download Files**: Get official v1.2 release and STM32CubeProgrammer
2. **Flash Bootloader**: Use STM32CubeProgrammer to flash AP_Bootloader.bin
3. **Test Official Project**: Upload and verify serial communication works
4. **Integrate with Orange Cube**: Customize for your DroneCAN application

### Questions for Support Follow-up
- Cable verification: Confirm using provided ST-LINK cable
- Debugging preference: Standard bootloader vs. breakpoint debugging
- Customization guidance: Best practices for modifying main.cpp

---

## EXPECTED OUTCOMES

After implementation:
- ✅ Serial communication working on COM8
- ✅ DroneCAN messages transmitting to Orange Cube
- ✅ Proper node identification on CAN bus
- ✅ Foundation for custom DroneCAN application development

This official solution should resolve both the serial communication issue and provide a robust foundation for DroneCAN implementation with the Orange Cube.

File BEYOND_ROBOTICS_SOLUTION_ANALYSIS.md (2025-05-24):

# Beyond Robotics Solution Analysis
## Official vs Custom Configuration Comparison

### PROBLEM IDENTIFIED ✅
Beyond Robotics support correctly identified that our custom PlatformIO configuration was missing proper Serial2 setup for the STM32L431 Micro Node.

---

## KEY DIFFERENCES: OFFICIAL vs CUSTOM

### 1. Board Configuration
**❌ Our Custom Config:**
```ini
board = nucleo_l432kc  ; Generic STM32L432 board
```

**✅ Official Config:**
```ini
board = BRMicroNode    ; Custom Beyond Robotics board definition
```

### 2. Serial Pin Mapping
**❌ Our Custom Config:**
- Using generic nucleo pin mapping
- Serial2 not properly configured for ST-LINK connection

**✅ Official Config:**
- Custom variant with proper pin mapping
- `Serial` uses PA2/PA3 (UART2) → connects to ST-LINK V3
- Defined in `variant_BRMICRONODE.h`:
  ```cpp
  #define PIN_SERIAL_RX         PA3
  #define PIN_SERIAL_TX         PA2
  ```

### 3. Bootloader Support
**❌ Our Custom Config:**
- No bootloader support
- Standard Arduino setup

**✅ Official Config:**
- AP bootloader integration
- `app_setup()` function required
- Custom linker script for bootloader compatibility

### 4. Project Structure
**❌ Our Custom Config:**
- Basic PlatformIO structure
- Missing DroneCAN library integration

**✅ Official Config:**
- Complete DroneCAN library included
- Proper board definitions and variants
- Working examples and documentation

---

## OFFICIAL CONFIGURATION ANALYSIS

### PlatformIO Configuration
```ini
[env:stm32L431]
platform = ststm32
board = BRMicroNode                    # Custom board definition
framework = arduino
upload_protocol = stlink
debug_tool = stlink
monitor_speed = 115200
board_build.variants_dir = variants    # Custom variant directory
board_build.ldscript = variants/BRMicroNode/ldscript.ld  # Custom linker
```

### Main.cpp Key Features
```cpp
void setup() {
    app_setup();              // Bootloader compatibility - CRITICAL!
    Serial.begin(115200);     # Uses PA2/PA3 → ST-LINK connection
    dronecan.init(...);       # Proper DroneCAN initialization
    // ... rest of setup
}
```

### Serial Communication
- **Serial** object automatically uses PA2/PA3 (UART2)
- PA2/PA3 are connected to ST-LINK header pins 13/14
- ST-LINK V3 provides Virtual COM Port on these pins
- No need for Serial2 - Serial is correctly mapped!

---

## WHY OUR CUSTOM CONFIG FAILED

### 1. Wrong Board Definition
- `nucleo_l432kc` has different pin mapping than Beyond Robotics hardware
- Serial pins not mapped to ST-LINK connection

### 2. Missing Variant Configuration
- No custom variant for Beyond Robotics pin layout
- Generic STM32L432 variant doesn't match hardware

### 3. No Bootloader Support
- Missing `app_setup()` function
- Wrong memory layout for bootloader

### 4. Incorrect Serial Usage
- Trying Serial2 when Serial is the correct interface
- Serial2 may not be configured in generic variant

---

## IMPLEMENTATION PLAN

### Phase 1: Flash Bootloader ⏳
1. Download STM32CubeProgrammer
2. Flash `AP_Bootloader.bin` to 0x8000000
3. Verify node boots in maintenance mode

### Phase 2: Use Official Project ⏳
1. Copy official project to new directory
2. Open in VSCode/PlatformIO
3. Upload firmware via PlatformIO
4. Test serial communication on COM8

### Phase 3: Verify Functionality ⏳
1. Confirm serial output at 115200 baud
2. Verify DroneCAN messages transmitting
3. Test communication with Orange Cube

### Phase 4: Customize Application ⏳
1. Modify `src/main.cpp` for your needs
2. Integrate with Orange Cube configuration
3. Test end-to-end DroneCAN communication

---

## EXPECTED RESULTS

After implementing official solution:
- ✅ Serial communication working on COM8
- ✅ Proper DroneCAN message transmission
- ✅ Node identification on CAN bus
- ✅ Foundation for custom application development

---

## SUPPORT RESPONSE VALIDATION

Beyond Robotics support was **100% correct**:
1. ✅ Identified custom config as root cause
2. ✅ Provided working official solution
3. ✅ Included proper bootloader for CAN updates
4. ✅ Gave complete project with examples

**Recommendation**: Follow their solution exactly as provided.

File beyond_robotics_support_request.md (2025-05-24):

# Beyond Robotics Dev Board - UART2 Serial Communication Support Request

## Subject: UART2 Serial Communication Issue with STM32L431 Micro Node via ST-LINK V3

Dear Beyond Robotics Support Team,

I am experiencing difficulties with UART2 serial communication on the Beyond Robotics Node Development Board with mounted STM32L431 Micro Node. After consulting your documentation, I understand that UART2 should be the console port for ST-LINK communication, but I cannot receive any serial output via COM8.

## Hardware Setup

- **Board**: Beyond Robotics Node Development Board with STM32L431 Micro Node
- **Programmer**: ST-LINK V3 MINI (blue dongle)
- **Connection**: ST-LINK V3 connected to STLINK header (pins 13/14 for UART2_TX/RX)
- **Switch Position**: SW1 set to position "1" (STLINK enabled, USB disabled)
- **Operating System**: Windows 11
- **Development Environment**: PlatformIO with Arduino framework

## Current Status

### ✅ Working:
- ST-LINK V3 is recognized by Windows (appears as "ST-Link Debug" and "USB Serial Device (COM8)")
- Chip detection successful (STM32L431 confirmed via documentation)
- Firmware upload successful using ST-LINK with nucleo_l432kc board configuration
- LED blinking confirms firmware is running
- Board reset functionality working
- Hardware connections verified with multimeter

### ❌ Not Working:
- No serial output received on COM8 at 115200 baud
- Virtual COM Port appears to be inactive
- Both Serial.begin(115200) and Serial2.begin(115200) produce no output
- UART2 (pins 13/14 on STLINK header) not responding

## Technical Details

### PlatformIO Configuration (Current Working):
```ini
[env:beyond_robotics_dev_board]
platform = ststm32
board = nucleo_l432kc  ; STM32L431 compatible board
framework = arduino
upload_protocol = stlink
debug_tool = stlink
monitor_speed = 115200
monitor_port = COM8
build_flags =
    -D ARDUINO_ARCH_STM32
    -D STM32L4xx
    -D BOARD_NAME="Beyond_Robotics_Dev_Board"
```

### Test Code (Both Serial and Serial2 Attempted):
```cpp
void setup() {
    pinMode(LED_BUILTIN, OUTPUT);

    // Try both Serial (UART1) and Serial2 (UART2)
    Serial.begin(115200);   // Standard Arduino serial
    Serial2.begin(115200);  // UART2 for ST-LINK (per documentation)
    delay(2000);

    Serial.println("Test message via Serial (UART1)");
    Serial2.println("Test message via Serial2 (UART2)");
}

void loop() {
    digitalWrite(LED_BUILTIN, HIGH);
    Serial.println("LED ON");
    Serial2.println("LED ON via UART2");
    delay(500);

    digitalWrite(LED_BUILTIN, LOW);
    Serial.println("LED OFF");
    Serial2.println("LED OFF via UART2");
    delay(500);
}
```

### Upload Configuration:
Upload works successfully with standard STM32L4 configuration (no custom OpenOCD needed).

## Questions

1. **UART2 Configuration**: Your documentation states that UART2 (pins 13/14 on STLINK header) is the console port. However, neither `Serial.begin(115200)` nor `Serial2.begin(115200)` produce output on COM8. Is there a specific configuration required to enable UART2 output via ST-LINK V3?

2. **Virtual COM Port**: Does the ST-LINK V3 connection automatically provide Virtual COM Port functionality for UART2, or does it require additional configuration/drivers?

3. **Board Configuration**: I'm currently using `board = nucleo_l432kc` for the STM32L431. Is this the correct PlatformIO board configuration for your Micro Node, or should I use a different board definition?

4. **Alternative Serial Debugging**: If ST-LINK serial doesn't work, should I use the JST-GH connectors (SERIAL1/SERIAL3) with an external USB-TTL adapter for debugging?

5. **SW1 Switch**: I have SW1 in position "1" (STLINK enabled). Is this correct for both programming AND serial debugging, or should it be changed after upload?

6. **Arduino Framework Compatibility**: Are there any known issues with the Arduino framework and UART2 on the STM32L431 that might prevent serial output?

## Intended Use Case

I am developing DroneCAN communication between the Beyond Robotics Dev Board and an Orange Cube autopilot. Serial debugging would be extremely helpful for monitoring CAN message traffic and troubleshooting the implementation.

## Request

Could you please provide:
- Correct PlatformIO configuration for serial communication
- Pin mapping for UART connections on your dev board
- Any specific setup requirements for ST-LINK V3 serial debugging
- Example code that demonstrates working serial output

I would greatly appreciate your guidance on this matter. The board appears to be functioning correctly otherwise, and I'm eager to proceed with the DroneCAN implementation once serial debugging is working.

Thank you for your time and support.

Best regards,

[Your Name]
[Your Email]
[Date]

---

## Additional Information

### System Information:
- Windows 11 Professional
- PlatformIO Core 6.1.x
- ST-LINK V3 firmware up to date
- All drivers installed via ST-LINK utility

### Troubleshooting Already Attempted:
- Verified COM port availability (COM8 accessible)
- Tested different baud rates (9600, 57600, 115200)
- Tried multiple board configurations (nucleo_f103rb, genericSTM32F103C8, nucleo_l432kc)
- Confirmed hardware reset functionality (LED blinking after reset)
- Verified LED blinking indicates firmware execution
- Tested both Serial.begin() and Serial2.begin() for UART1/UART2
- Confirmed ST-LINK V3 driver installation and recognition
- Verified hardware connections with multimeter
- Tested with minimal serial output code on STM32L431 configuration

### Hardware Verification:
- Multimeter confirmed proper connections
- ST-LINK V3 LED indicators show normal operation
- Board power supply stable
- No physical damage visible

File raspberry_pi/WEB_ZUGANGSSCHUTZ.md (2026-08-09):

# Zugangsschutz für die öffentlich erreichbaren Weboberflächen

Stand: 07.08.2026

Steuerungsoberfläche und SensorHub hängen über Portfreigaben direkt am
Internet. Beide verlangen seitdem eine Anmeldung per HTTP-Basic-Auth. Diese
Datei beschreibt, wie die Passwörter gesetzt werden und was der Schutz leistet.

## Erreichbarkeit (gemessen am 07.08.2026)

| Öffentlicher Port | Ziel | Intern |
|---|---|---|
| 8080 | Raspberry Steuerungsoberfläche | `raspberrycan:80` |
| 8081 | SensorHub | `orangeugv:80` |
| 80, 443 | anderes Gerät im Netz (nginx), **nicht** das UGV | — |

Zur Prüfung von außen dient die Kennung im Antwortkopf: Der Raspberry meldet
`WWW-Authenticate: Basic realm="Quassel UGV"`, der SensorHub
`realm="Quassel UGV SensorHub"`. Antwortet ein Port stattdessen mit
`Server: nginx`, ist es nicht das Fahrzeug.

## Was ohne Schutz erreichbar war

| Endpunkt | Wirkung |
|---|---|
| `POST /api/joystick`, WebSocket `joystick_update` | Fahrzeug fahren |
| `POST /api/mower/toggle` | Mähmesser starten |
| `POST /api/mapping/maps/<name>/plan/execute` | autonome Mahd starten |
| `POST /api/safety/reset` | Sicherheitsverriegelung aufheben |
| SensorHub `GET /api/telemetry` | metergenaue Position des Grundstücks |

## Passwörter setzen

### Raspberry (Steuerungsoberfläche)

Das Passwort steht **nicht** in der `config.yaml` und auch nicht in der
Service-Unit — Unit-Dateien sind für alle lokalen Benutzer lesbar. Es liegt in
`/etc/ugv-web.env` mit Modus 600, die die Unit über `EnvironmentFile=` einliest:

```
UGV_WEB_USERNAME=smart
UGV_WEB_PASSWORD=hier-ein-langes-passwort
UGV_WEB_SECRET_KEY=hier-ein-zufaelliger-wert
SENSOR_HUB_TELEMETRY_USER=smart
SENSOR_HUB_TELEMETRY_PASSWORD=passwort-des-sensorhubs
UGV_NTFY_TOPIC=zufaelliger-topic-name
```

`UGV_NTFY_TOPIC` ist das Ziel der Störungsmeldungen. Bei `ntfy.sh` kann jeder
mitlesen und mitschreiben, der den Topic-Namen kennt — er gehört deshalb hierher
und nicht in die `config.yaml`. Details in
[motor_controller/README.md](motor_controller/README.md#-push-meldungen-bei-störungen).

Rechte setzen und übernehmen:

```bash
sudo chown root:root /etc/ugv-web.env && sudo chmod 600 /etc/ugv-web.env && sudo systemctl restart motor-controller-v2
```

Weil die Datei nur root gehört, kommt auch das Deploy-Skript nur über `sudo`
an sie heran — die Abschlussprüfung dort liest sie entsprechend.

Besser als das Passwort im Klartext ist ein Hash. Er wird auf dem Raspberry
erzeugt und in dieselbe Variable eingetragen:

```bash
python3 -c "from werkzeug.security import generate_password_hash; print(generate_password_hash(input('Passwort: ')))"
```

Ein zufälliges Passwort und einen Sitzungsschlüssel erzeugst du mit:

```bash
python3 -c "import secrets; print(secrets.token_urlsafe(24))"
```

Danach:

```bash
sudo systemctl daemon-reload && sudo systemctl restart motor-controller-v2
```

### SensorHub (Orange Pi)

Der SensorHub liest seine Konfiguration aus `/opt/sensor_hub/.env`:

```
WEB_AUTH_USERNAME=ugv
WEB_AUTH_PASSWORD=hier-ein-langes-passwort
```

Rechte einschränken und neu starten:

```bash
sudo chmod 600 /opt/sensor_hub/.env && sudo systemctl restart sensor-hub.service
```

### Wichtig: der Raspberry ist selbst ein Client des SensorHub

Der Raspberry holt seine Pose über `sensor_hub.wifi_url` vom SensorHub. Diese
Zugangsdaten müssen zusammenpassen:

| SensorHub (`.env`) | Raspberry |
|---|---|
| `WEB_AUTH_USERNAME` | `sensor_hub.auth_username` in der `config.yaml` |
| `WEB_AUTH_PASSWORD` | `SENSOR_HUB_TELEMETRY_PASSWORD` in der Dienst-Umgebung |

Passen sie nicht zusammen, bleibt die Pose aus und der Watchdog pausiert nach
etwa einer Sekunde Fahrantrieb und Route. Im Journal steht dann:

```
SensorHub weist die Anmeldung ab ...
```

### Reihenfolge beim Ausrollen: Raspberry zuerst

Ein SensorHub, der bereits Anmeldung verlangt, während der Raspberry noch alten
Code fährt, antwortet diesem mit 401 — Pose weg, Fahrantrieb pausiert.
Andersherum ist es unkritisch: Ein Raspberry, der Zugangsdaten mitschickt,
kommt an einem SensorHub, der noch keine verlangt, problemlos durch. Der
zusätzliche Header wird schlicht ignoriert.

1. Zugangsdaten auf **beiden** Geräten hinterlegen (die alte SensorHub-Version
   ignoriert `WEB_AUTH_*`, das ist gefahrlos)
2. **Raspberry** ausrollen und neu starten
3. **SensorHub** ausrollen und neu starten
4. `journalctl -u motor-controller-v2 -f` kontrollieren

Nach Schritt 3 erscheint einmalig `SensorHub-Telemetriestrom beendet` — das ist
der Abriss durch den Dienstneustart, kein Fehler. Bleibt es dabei und meldet
der Status `motion_allowed: true`, ist die Kette intakt.

## Was der Schutz leistet

- **Anmeldung für jede Route.** Ohne gültige Zugangsdaten antworten beide
  Server mit 401, auch auf Statusabfragen.
- **WebSocket abgesichert.** Der Socket.IO-Handshake läuft am HTTP-Hook vorbei
  und wird separat über das Sitzungscookie geprüft. Ohne diese Prüfung wäre
  `joystick_update` ein unauthentifizierter Steuerkanal geblieben.
- **Kein Wildcard-CORS mehr.** Vorher stand auf jeder Antwort
  `Access-Control-Allow-Origin: *`; jede beliebige Webseite konnte damit
  Antworten dieses Servers lesen.
- **Schutz vor fremden Webseiten.** Ein Browser hängt einmal eingegebene
  Basic-Auth-Zugangsdaten auch an Requests an, die eine fremde Seite auslöst.
  Schreibende Requests mit fremder Herkunft (`Origin` / `Sec-Fetch-Site`)
  werden deshalb mit 403 abgewiesen. Skripte ohne Browser-Header bleiben
  erlaubt, weil das Basic-Auth sie bereits abfängt.
- **Bremse gegen Rateversuche.** Nach `auth_max_failures` Fehlversuchen ist die
  Quell-IP für `auth_lockout_s` Sekunden gesperrt.
- **Fail closed.** Ist der Schutz aktiv, aber kein Passwort gesetzt, antwortet
  der Server mit 503 statt ungeschützt zu laufen.
- **Keine Geheimnisse in der YAML.** `to_yaml()` schreibt weder Passwörter noch
  den `secret_key`.

## Was der Schutz nicht leistet

Basic-Auth ohne TLS überträgt das Passwort bei **jedem** Request mitlesbar.
Jeder Netzknoten zwischen deinem Handy und dem Grundstück sieht es: fremdes
WLAN, Mobilfunknetz, jeder Hop dazwischen. Der Schutz hält Gelegenheitsfunde
und Portscanner ab, nicht jemanden, der deinen Datenverkehr beobachtet.

### Nachrüsten von TLS

Hier gibt es zwei Hindernisse, die man kennen sollte, bevor man anfängt.

**Die Ports 80 und 443 sind belegt.** Sie zeigen auf ein anderes Gerät im Netz,
nicht auf das UGV. Let's Encrypt braucht aber genau einen von beiden für den
Besitznachweis (HTTP-01 auf 80, TLS-ALPN-01 auf 443). Ein Caddy auf dem
Raspberry käme also gar nicht an ein Zertifikat, solange die Freigaben so
stehen.

**Die Uhr.** Weder Raspberry noch Orange Pi haben ein RTC-Modul, und beide sind
über den Winter aus. Nach Monaten ohne Strom booten sie mit falschem Datum; bis
NTP durchgelaufen ist, scheitert jede Zertifikatsausstellung. Ein Dienst, der
darauf angewiesen ist, bräuchte eine Startbedingung auf `time-sync.target`.

Beides zusammen spricht dafür, TLS **nicht** auf dem Fahrzeug zu betreiben,
sondern auf dem Gerät, das ohnehin schon 80 und 443 hält, durchgehend läuft und
eine korrekte Uhr hat. Es würde als Reverse Proxy vor die UGV-Oberfläche
gesetzt und das Zertifikat verwalten; auf dem Fahrzeug bliebe alles wie es ist.
Die Origin-Prüfung akzeptiert `https` auf demselben Host bereits, es wäre also
keine Codeänderung nötig.

**Wichtig dabei:** Der Telemetriepfad Raspberry → SensorHub darf nicht über
einen TLS-Proxy laufen. Python bricht bei abgelaufenem Zertifikat hart ab, es
gibt kein Wegklicken — ein abgelaufenes Zertifikat würde damit den Fahrantrieb
stilllegen. Diese Verbindung bleibt auf reinem HTTP.

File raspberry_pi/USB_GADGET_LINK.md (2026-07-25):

# USB-Gadget-Link zwischen Orange Pi (SensorHub) und Raspberry Pi

Alternative zum WLAN für die SensorHub-Telemetrie: Der Orange Pi Zero 2W stellt
über seinen freien OTG-USB-C-Port ein CDC-ECM-Gadget (`g_ether` via
configfs/libcomposite) bereit, der Raspberry Pi ist USB-Host. Ergebnis ist ein
Punkt-zu-Punkt-Ethernet-Link mit statischen IPs:

| Seite | Rolle | Interface | IP |
|---|---|---|---|
| Orange Pi Zero 2W | USB-Gadget (Device) | `usb0` | `10.66.0.1/24` |
| Raspberry Pi 3 | USB-Host (`cdc_ether`) | `usb0` | `10.66.0.2/24` |

Der HTTP-Pfad im Code bleibt unverändert – es wandert nur die URL in
`config.yaml`. Es gibt **bewusst keinen Auto-Fallback** zwischen WLAN und
USB-Link; die Umstellung ist explizit manuell. Wer zurück will, stellt die
alte `wifi_url` wieder ein.

Die Stromversorgung des Orange Pi läuft weiter über den eigenen Power-Port,
nicht über den OTG-Port. Das Verbindungskabel muss Datenleitungen haben
(kein reines Ladekabel).

## 1. Orange Pi (Gadget-Seite)

Skript und Unit liegen unter `sensor_hub/scripts/` und werden wie die übrigen
SensorHub-Artefakte nach `/opt/sensor_hub` deployt (siehe
`sensor_hub/DEPLOY_ORANGE_PI.md`):

```bash
sudo install -m 755 /opt/sensor_hub/scripts/usb_gadget_setup.sh /usr/local/bin/usb_gadget_setup.sh
sudo install -m 644 /opt/sensor_hub/scripts/usb-gadget.service /etc/systemd/system/usb-gadget.service
sudo systemctl daemon-reload
sudo systemctl enable --now usb-gadget.service
```

Das Skript lädt `libcomposite`, legt das Gadget `ecm.usb0` mit festen MACs an
(Device `02:11:22:33:44:01`, Host `02:11:22:33:44:02`) und setzt
`10.66.0.1/24` auf `usb0`. USB-IDs: `0x1d6b:0x0104` (Linux Foundation
Multifunction Composite Gadget) – eine unverfängliche, öffentlich
dokumentierte Kombination.

Voraussetzung: Der OTG-Controller muss im Device-Tree auf
`dr_mode = "peripheral"` (oder `"otg"`) stehen. Schnellcheck:

```bash
ls /sys/class/udc        # muss mindestens einen Eintrag liefern
```

Ist das Verzeichnis leer, auf Armbian/DietPi das Overlay `usb-otg` aktivieren
(`armbian-config` bzw. `/boot/armbianEnv.txt` bzw. `dietpi-config`) und neu
starten. Das Setup-Skript bricht in dem Fall mit einem entsprechenden Hinweis
ab. Bei mehreren UDCs kann der gewünschte per Env-Var `UDC` gewählt werden.

## 2. Raspberry Pi (Host-Seite)

Nach dem Anstecken meldet sich das Gadget als CDC-ECM-Gerät (`cdc_ether`),
das Interface heißt typischerweise `usb0`:

```bash
lsusb                  # ... ID 1d6b:0104 Linux Foundation Multifunction Composite Gadget
ip addr show usb0
```

### Statische IP per dhcpcd (Raspberry Pi OS Standard)

In `/etc/dhcpcd.conf` ergänzen:

```
interface usb0
static ip_address=10.66.0.2/24
nogateway
```

Danach `sudo systemctl restart dhcpcd` (oder neu starten). `nogateway`
verhindert, dass der Link die Default-Route vom WLAN/Ethernet wegzieht.

### Alternative: systemd-networkd

Falls das System `systemd-networkd` statt `dhcpcd` nutzt,
`/etc/systemd/network/20-ugv-usb0.network`:

```ini
[Match]
Name=usb0

[Network]
Address=10.66.0.2/24
```

Dann `sudo systemctl enable --now systemd-networkd` und `sudo networkctl reload`.

### udev-Regel, falls das Interface anders heißt

Vergibt das System einen persistierten Namen (z. B. `enx021122334402`), kann
das Interface anhand der Host-MAC `02:11:22:33:44:02` auf `usb0` festgepinnt
werden – `/etc/udev/rules.d/70-ugv-ecm.rules`:

```
SUBSYSTEM=="net", ACTION=="add", ATTR{address}=="02:11:22:33:44:02", NAME="usb0"
```

Danach neu starten (udev benennt nur beim Anlegen des Interfaces um).
Alternativ den tatsächlichen Namen in den Snippets oben verwenden.

## 3. Telemetrie auf den USB-Link umstellen

In `config.yaml` (Block `sensor_hub`, siehe `motor_controller/config.py`) nur
die URL ändern – `transport: wifi` bleibt stehen, es ist derselbe
HTTP-Transport, nur über ein anderes Netz:

```yaml
sensor_hub:
  transport: wifi
  wifi_url: http://10.66.0.1/api/telemetry
```

Der Default in `config.py` (`http://192.168.178.20/api/telemetry`) bleibt
unverändert, damit WLAN weiterhin als Rückfall per Konfiguration verfügbar
ist. Danach den Motor-Controller-Dienst neu starten.

## 4. Verifikation

Auf dem Raspberry Pi:

```bash
lsusb                                   # Gadget mit ID 1d6b:0104 sichtbar
ip addr show usb0                       # inet 10.66.0.2/24
ping -c 3 10.66.0.1                     # Orange Pi antwortet
curl http://10.66.0.1/api/telemetry     # Telemetrie-JSON
```

Auf dem Orange Pi:

```bash
sudo /usr/local/bin/usb_gadget_setup.sh status
ip addr show usb0                       # inet 10.66.0.1/24
journalctl -u usb-gadget.service --no-pager
```

## 5. Troubleshooting

- **`/sys/class/udc` auf dem Orange Pi ist leer:** OTG-Controller steht nicht
  im Peripheral-Modus → Device-Tree/Overlay `usb-otg` aktivieren
  (`armbian-config` / `armbianEnv.txt` / `dietpi-config`), neu starten.
  Das ist der bekannte Knackpunkt auf dem H618.
- **Interface heißt anders (`enx...`):** udev-Regel aus Abschnitt 2 setzen
  oder den Namen im dhcpcd/networkd-Snippet anpassen. Am Orange Pi sucht das
  Setup-Skript das Interface notfalls anhand der Device-MAC selbst.
- **Kein `usb0` am Raspberry, nichts in `lsusb`:** Kabel ohne Datenleitungen
  (reines Ladekabel) oder falscher USB-C-Port am Orange Pi – es muss der
  OTG-fähige Port sein.
- **Link da, aber keine Route ins restliche Netz:** Absicht – der Link ist
  Punkt-zu-Punkt. Am Raspberry `nogateway` (dhcpcd) bzw. kein `Gateway=` in
  networkd gesetzt lassen.
- **Zurück zu WLAN:** `wifi_url` in `config.yaml` auf die alte Adresse
  setzen, Dienst neu starten. `usb-gadget.service` kann parallel aktiv
  bleiben, er stört das WLAN nicht.

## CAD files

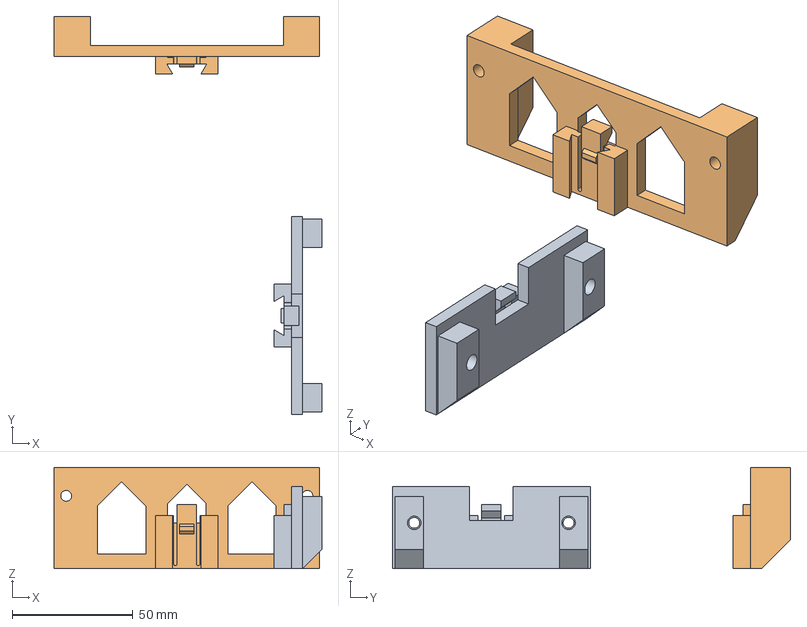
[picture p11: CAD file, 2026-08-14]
cad/halterung_baugruppe.step
111.0 x 165.0 x 42.0 mm

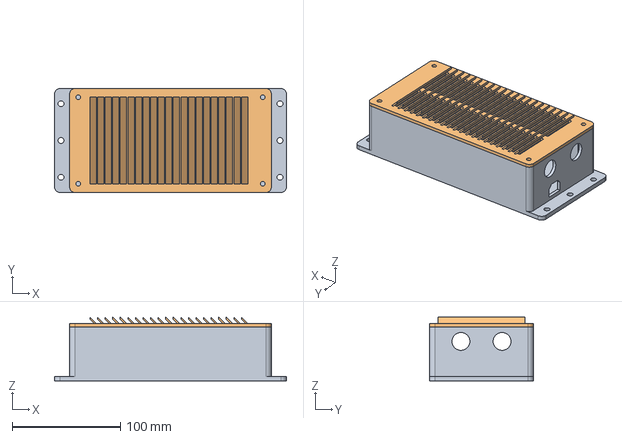
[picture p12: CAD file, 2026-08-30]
cad/odrive35_box.step
214.5 x 96.0 x 59.0 mm

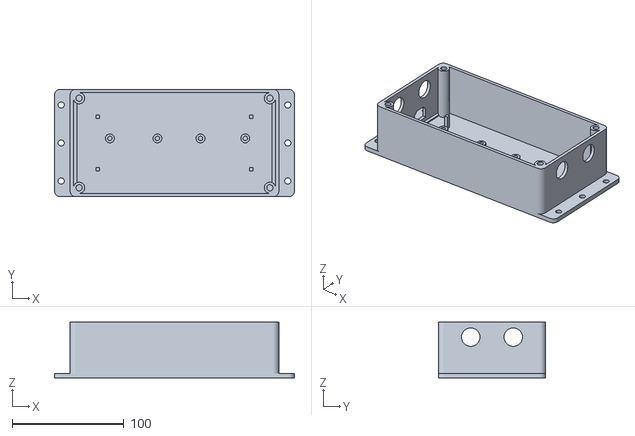
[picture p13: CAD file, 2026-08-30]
cad/asa_odrive35_box_base.stl
214.5 x 96.0 x 50.0

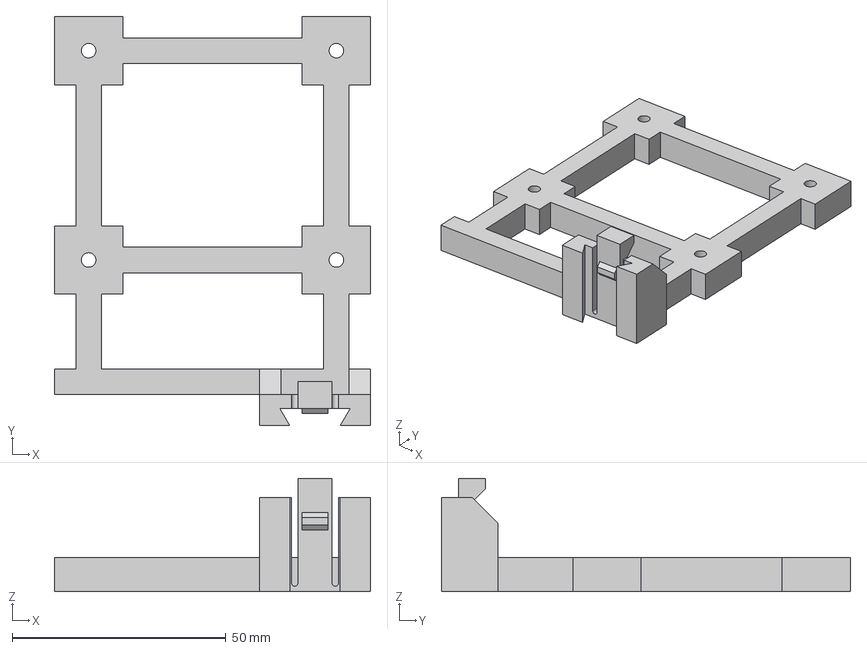
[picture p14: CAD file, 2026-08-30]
cad/pi3_halter.step
74.0 x 95.8 x 26.5 mm

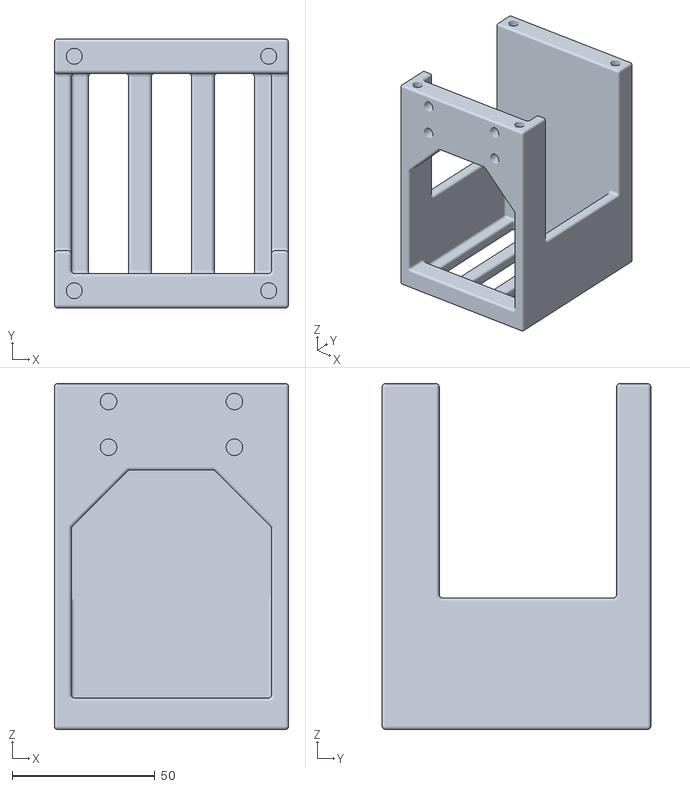
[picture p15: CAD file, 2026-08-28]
cad/asa_router_e5180_wanne.stl
82.0 x 94.0 x 121.0

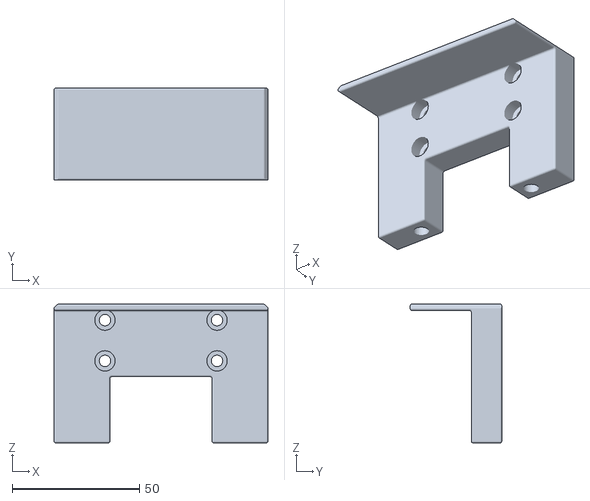
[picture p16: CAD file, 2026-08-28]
cad/asa_router_e5180_schelle_oben.stl
84.0 x 36.0 x 54.5

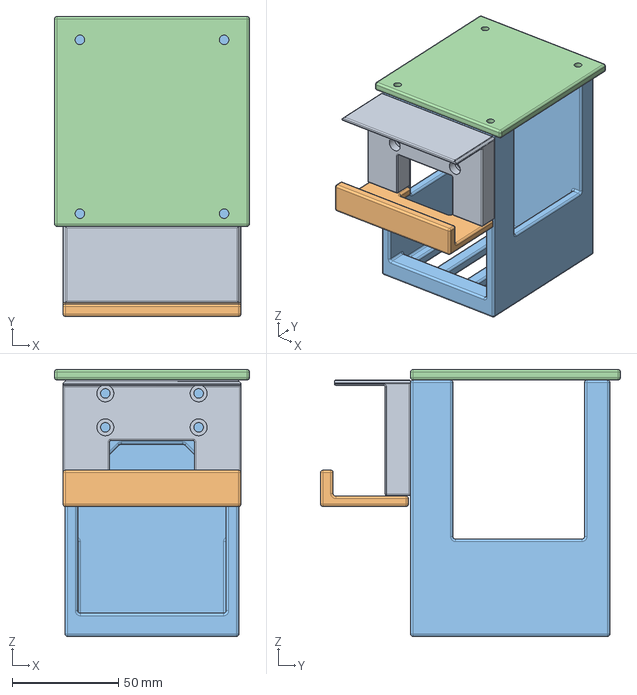
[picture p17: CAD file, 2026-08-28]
cad/router_e5180_halter.step
92.0 x 141.5 x 126.0 mm

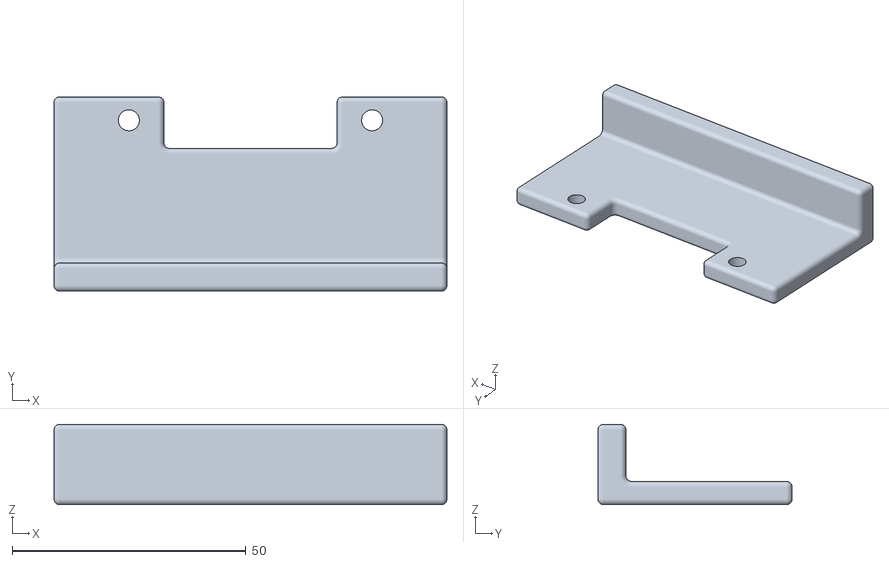
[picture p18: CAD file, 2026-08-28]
cad/asa_router_e5180_schelle_strap.stl
84.0 x 41.5 x 17.2

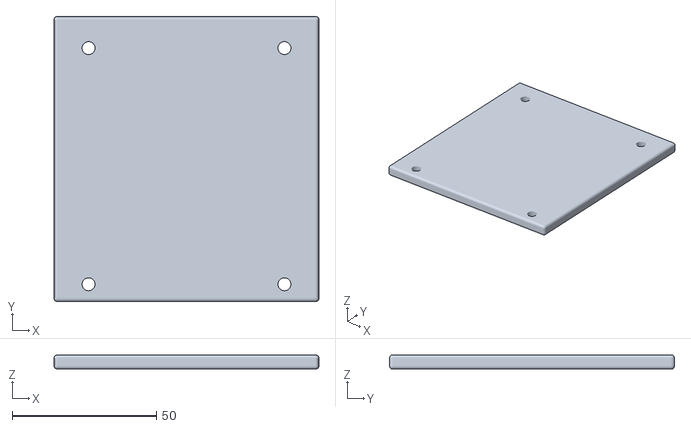
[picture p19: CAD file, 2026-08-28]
cad/asa_router_e5180_dach.stl
92.0 x 99.0 x 5.00

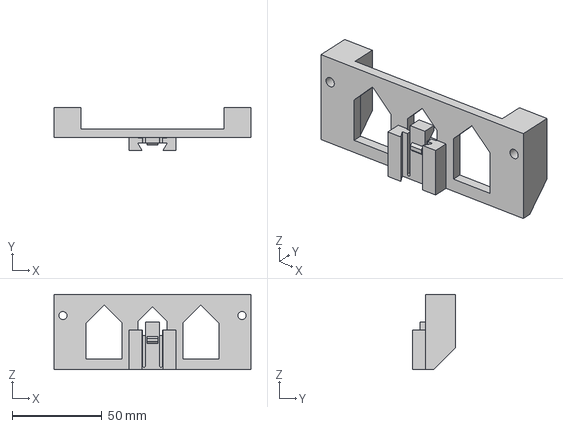
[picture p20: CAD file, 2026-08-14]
cad/junctek_halter.step
110.0 x 23.8 x 42.0 mm

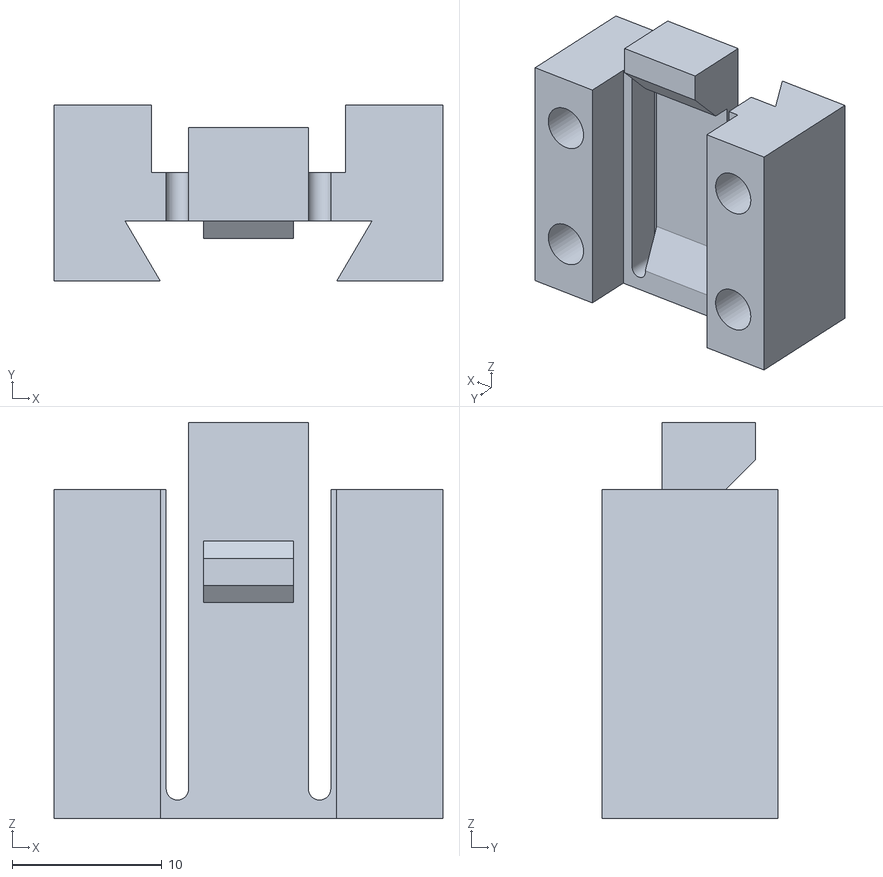
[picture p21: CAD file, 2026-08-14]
cad/asa_snap_adapter.stl
26.0 x 11.8 x 26.5

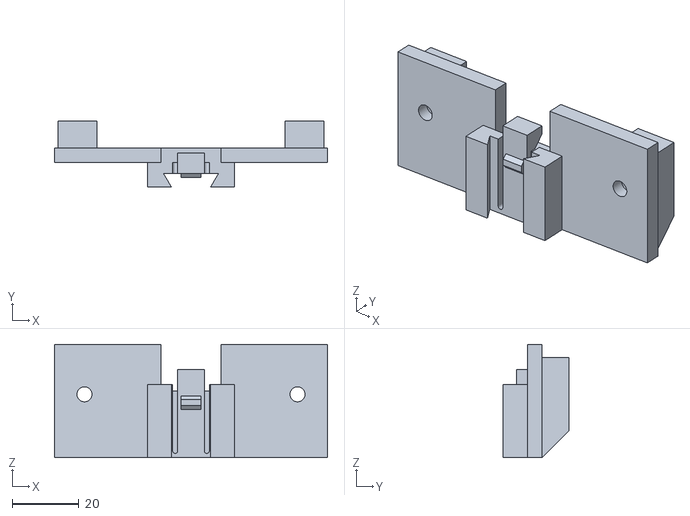
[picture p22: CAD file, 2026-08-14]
cad/asa_shunt_halter.stl
82.0 x 19.8 x 34.0

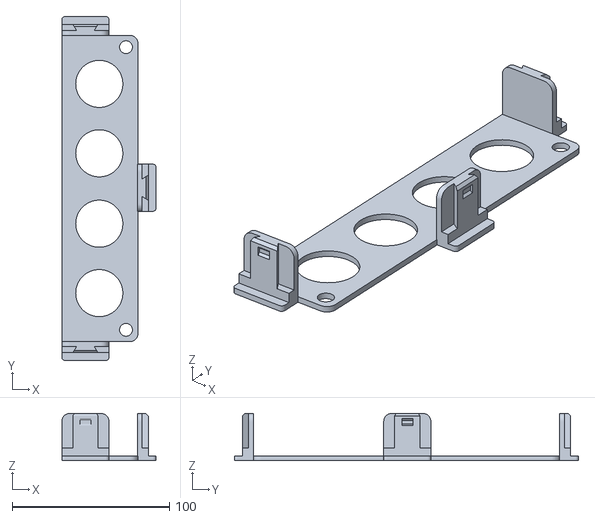
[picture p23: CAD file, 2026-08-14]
cad/asa_halterung_batterie_snap.stl
60.0 x 219.0 x 30.0

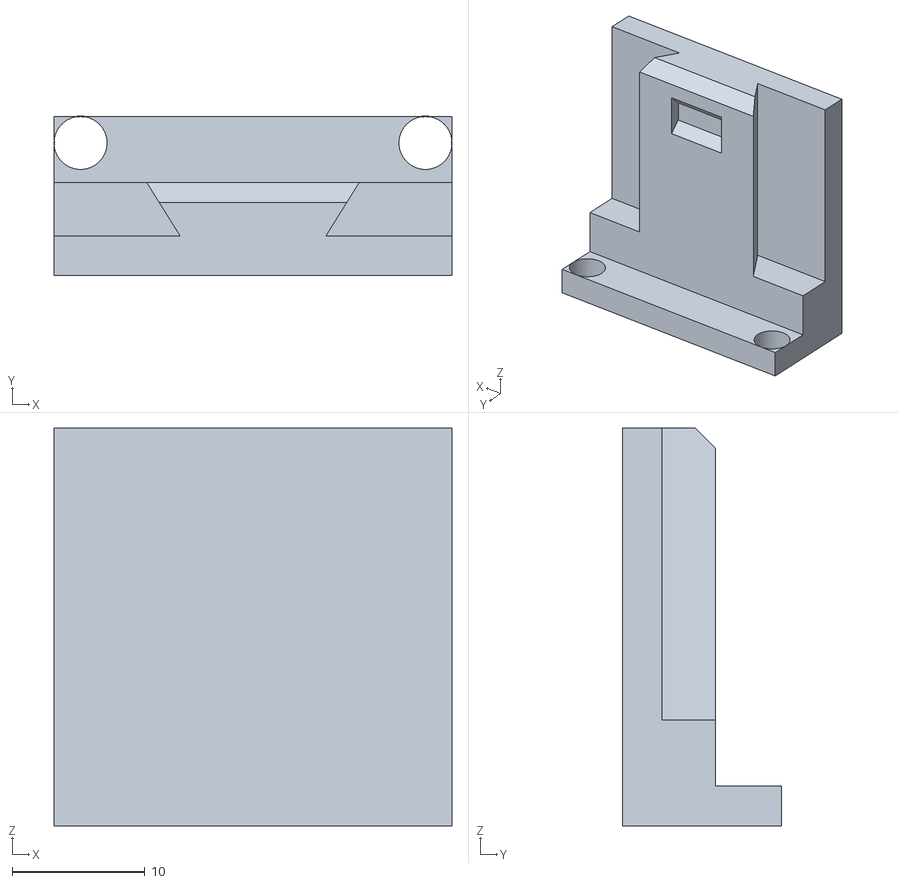
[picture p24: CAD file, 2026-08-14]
cad/asa_snap_rail_pruefklotz.stl
30.0 x 12.0 x 30.0

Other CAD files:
cad/asa_pi3_halter.stl
cad/asa_junctek_halter.stl
cad/shunt_halter.step
cad/halterung_batterie_snap.step
cad/asa_odrive35_box_lid.stl
cad/asa_outrunner_guard_d5065_louvers.step
cad/asa_outrunner_guard_d5065_louvers.stl
cad/asa_outrunner_guard_d5065_test.stl
cad/snap_interface.step

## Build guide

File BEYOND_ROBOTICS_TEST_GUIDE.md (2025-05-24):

# Beyond Robotics CAN Node Test Guide

## Hardware Setup

### 1. STM-LINK V3 Programmer
- ✅ **Erkannt als**: "ST-Link Debug" und "Serielles USB-Gerät (COM8)"
- ✅ **USB-Kabel funktioniert** (Datenübertragung möglich)
- ✅ **Treiber installiert**

### 2. Beyond Robotics Dev Board Konfiguration
- **SW1 auf Position "1"** (STLINK aktiviert, USB-zu-UART deaktiviert)
- **STM-LINK V3 mit STLINK-Header verbinden**
- **CAN-Verbindung**: CANH/CANL zwischen Dev Board und Orange Cube
- **GND-Verbindung** zwischen Dev Board und Orange Cube

### 3. Orange Cube Setup
- ✅ **Orange Cube bereits konfiguriert** mit optimierten DroneCAN-Parametern
- ✅ **Sendet regelmäßig DroneCAN-Nachrichten** (bestätigt mit Cangaroo)

## Test-Dateien

### 1. `beyond_robotics_can_test.cpp`
**Haupttest-Programm** mit folgenden Funktionen:
- **CAN-Nachrichten empfangen** und dekodieren
- **Heartbeat senden** (alle 1 Sekunde)
- **Statistiken anzeigen** (alle 5 Sekunden)
- **Detaillierte Ausgabe** aller empfangenen Nachrichten

### 2. `platformio_beyond_robotics.ini`
**PlatformIO-Konfiguration** für das Beyond Robotics Dev Board:
- STM32F103RB Mikrocontroller
- STM-LINK Upload und Debug
- COM8 für serielle Ausgabe

### 3. `run-beyond-robotics-test.bat`
**Automatisches Upload und Monitor-Script**

## Test durchführen

### Schritt 1: Hardware vorbereiten
```
1. STM-LINK V3 mit PC verbinden (USB)
2. STM-LINK V3 mit Beyond Robotics Dev Board verbinden (STLINK-Header)
3. SW1 auf Position "1" setzen
4. CAN-Verbindung: CANH/CANL zwischen Dev Board und Orange Cube
5. Orange Cube einschalten und mit Mission Planner verbinden
```

### Schritt 2: Test starten
```
run-beyond-robotics-test.bat
```

### Schritt 3: Erwartete Ausgabe
```
=== Beyond Robotics CAN Node Test ===
Testing DroneCAN communication with Orange Cube
Hardware: Beyond Robotics Dev Board + STM-LINK V3
CAN Speed: 500 kbps
Serial Output: COM8
=====================================
Initializing DroneCAN...
DroneCAN initialized successfully!
Listening for CAN messages from Orange Cube...
Expected messages:
- NodeStatus (Heartbeat)
- ESC Status
- Servo Commands
- Battery Info
=====================================
Sent heartbeat #1
[RX] Node ID: 10 | Data Type ID: 341 | Transfer ID: 5 | Payload Length: 7 bytes | Type: NodeStatus (Heartbeat) | Health: 0 | Mode: 0 | Uptime: 123s
    Payload: 7B 00 00 00 00 00 00
[RX] Node ID: 10 | Data Type ID: 1034 | Transfer ID: 3 | Payload Length: 14 bytes | Type: ESC Status
    Payload: 00 00 00 00 FF FF FF FF
=== STATS === Total messages received: 15 | Uptime: 5 seconds
```

## Troubleshooting

### Problem: Upload fehlgeschlagen
**Lösung:**
- STM-LINK V3 Verbindung prüfen
- SW1 auf Position "1" prüfen
- Beyond Robotics Dev Board richtig am STLINK-Header angeschlossen

### Problem: Keine CAN-Nachrichten empfangen
**Lösung:**
- CAN-Verkabelung prüfen (CANH/CANL/GND)
- Orange Cube läuft und sendet Nachrichten (mit Cangaroo testen)
- Termination-Widerstände prüfen

### Problem: COM8 nicht verfügbar
**Lösung:**
- STM-LINK V3 Treiber neu installieren
- Anderen USB-Port versuchen
- Geräte-Manager prüfen

## Erfolg-Kriterien

✅ **Upload erfolgreich**: Programm wird ohne Fehler hochgeladen
✅ **Heartbeat gesendet**: "Sent heartbeat #X" Nachrichten erscheinen
✅ **CAN-Nachrichten empfangen**: "[RX]" Nachrichten vom Orange Cube
✅ **Statistiken**: Regelmäßige Statistik-Updates alle 5 Sekunden

## Nächste Schritte

Nach erfolgreichem Test können Sie:
1. **Spezifische DroneCAN-Nachrichten senden** (Actuator Commands)
2. **Sensor-Daten über DroneCAN übertragen**
3. **Custom DroneCAN-Nodes entwickeln**

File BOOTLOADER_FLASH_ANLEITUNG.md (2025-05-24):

# 🔧 Bootloader Flash Anleitung
## Beyond Robotics AP Bootloader Installation

### ✅ HARDWARE-STATUS BESTÄTIGT
- ✅ COM8 verfügbar (ST-LINK V3)
- ✅ Orange Cube auf COM4 aktiv
- ✅ Bootloader-Datei bereit: `beyond_robotics_working/AP_Bootloader.bin`

---

## 📋 SCHRITT-FÜR-SCHRITT ANLEITUNG

### 1. Hardware-Verbindung prüfen
**Vor dem Flashen sicherstellen:**
- ✅ ST-LINK V3 mit PC verbunden (USB)
- ✅ **Originalkabel** zwischen ST-LINK und Dev Board verwenden (wichtig!)
- ✅ SW1 in Position "1" (STLINK enabled)
- ✅ Dev Board mit Strom versorgt
- ✅ LED am Board sichtbar

### 2. STM32CubeProgrammer starten
1. STM32CubeProgrammer öffnen
2. **Connection Type**: "ST-LINK" auswählen
3. **Connect** klicken
4. **Erwartung**: STM32L431 wird erkannt

### 3. Bootloader flashen
**Datei-Pfad:**
```
C:\Users\mausz\Documents\PlatformIO\Projects\UGV ESP32CAN\beyond_robotics_working\AP_Bootloader.bin
```

**Flash-Einstellungen:**
- **File Path**: Zu obiger Datei navigieren
- **Start Address**: `0x8000000` (genau so eingeben!)
- **Verify**: Aktiviert lassen

**Flash-Prozess:**
1. "Erasing & Programming" Tab öffnen
2. File Path setzen
3. Start Address eingeben: `0x8000000`
4. **"Start Programming"** klicken

### 4. Erfolg verifizieren
**Erwartete Ausgabe:**
```
Connecting to target...
Connection established
Erasing memory...
Programming...
Verifying...
Programming completed successfully
```

**Nach dem Flash:**
- Board reset (Reset-Button drücken)
- LED-Verhalten beobachten
- Node sollte in "Maintenance Mode" booten

---

## 🎯 NÄCHSTER SCHRITT: FIRMWARE UPLOAD

Nach erfolgreichem Bootloader-Flash:

### Firmware via PlatformIO uploaden
```bash
cd beyond_robotics_working
pio run --target upload
```

**Oder mit unserem Script:**
```bash
upload_firmware.bat
```

### Serial Monitor testen
```bash
pio device monitor --port COM8 --baud 115200
```

**Oder mit unserem Script:**
```bash
monitor_serial.bat
```

---

## 🔍 ERWARTETE ERGEBNISSE

### Nach Bootloader-Flash:
- ✅ STM32CubeProgrammer meldet Erfolg
- ✅ Board bootet in Maintenance Mode
- ✅ Bereit für Firmware-Upload

### Nach Firmware-Upload:
- ✅ Serial-Kommunikation auf COM8
- ✅ DroneCAN-Nachrichten sichtbar
- ✅ Parameter-Ausgaben (PARM_1 = 69)
- ✅ Battery-Info alle 100ms
- ✅ CPU-Temperatur-Readings

### Beispiel Serial-Output:
```
PARM_1 value: 69
[DroneCAN initialization messages]
[Battery info messages every 100ms]
[CPU temperature readings]
```

---

## 🚨 TROUBLESHOOTING

### Problem: Kann nicht verbinden
**Lösungen:**
- ST-LINK Treiber neu installieren
- Anderer USB-Port versuchen
- SW1 Position prüfen
- Originalkabel verwenden

### Problem: Programming failed
**Lösungen:**
- Start Address nochmal prüfen: `0x8000000`
- Chip erst löschen, dann programmieren
- Board power-cycle

### Problem: Node bootet nicht
**Lösungen:**
- Reset-Button drücken
- Power-Cycle durchführen
- CAN-Bus Verbindung prüfen

---

## 📞 SUPPORT

Bei Problemen:
- **Beyond Robotics**: admin@beyondrobotix.com
- **Dokumentation**: https://beyond-robotix.gitbook.io/docs/

---

## ✨ BEREIT FÜR NÄCHSTEN SCHRITT

Sobald der Bootloader erfolgreich geflasht ist, können wir mit dem Firmware-Upload fortfahren und endlich die Serial-Kommunikation testen!

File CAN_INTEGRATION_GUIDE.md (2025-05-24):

# 🚀 CAN-Bus Integration Guide
## Beyond Robotics Board ↔ Orange Cube DroneCAN

### ✅ AKTUELLER STATUS
- ✅ Beyond Robotics Board: DroneCAN läuft, Node ID 127
- ✅ Orange Cube: DroneCAN konfiguriert, Node ID 10
- ✅ Beide Geräte: 1 Mbps Bitrate
- ✅ Serial-Kommunikation funktioniert

---

## 🔌 HARDWARE-VERBINDUNG

### Beyond Robotics Dev Board CAN-Pins
**Laut Beyond Robotics Dokumentation:**
- **CAN_TX**: Pin wird automatisch konfiguriert
- **CAN_RX**: Pin wird automatisch konfiguriert
- **CAN-Transceiver**: Integriert im Board

### Orange Cube CAN-Port
**Orange Cube Carrier Board:**
- **CAN1 Port**: 4-Pin JST-GH Connector
- **Pin 1**: VCC (5V)
- **Pin 2**: CAN_H
- **Pin 3**: CAN_L  
- **Pin 4**: GND

### Verbindungsschema
```
Beyond Robotics Board    Orange Cube CAN1
├─ CAN_H        ←────→   Pin 2 (CAN_H)
├─ CAN_L        ←────→   Pin 3 (CAN_L)
└─ GND          ←────→   Pin 4 (GND)
```

**WICHTIG:** 
- 120Ω Terminierung an beiden Enden
- Orange Cube hat bereits interne Terminierung
- Beyond Robotics Board sollte auch Terminierung haben

---

## ⚙️ SOFTWARE-KONFIGURATION

### Orange Cube Parameter (bereits gesetzt)
```
CAN_P1_DRIVER = 1         # CAN-Treiber aktiviert
CAN_P1_BITRATE = 1000000  # 1 Mbps
CAN_D1_PROTOCOL = 1       # DroneCAN aktiviert
CAN_D1_UC_NODE = 10       # Orange Cube Node ID
CAN_D1_UC_ESC_BM = 5      # ESC Bitmask
CAN_D1_UC_SRV_BM = 5      # Servo Bitmask
```

### Beyond Robotics Node ID anpassen
**Aktuell:** Node ID 127 (default)
**Empfohlen:** Node ID 20-50 (vermeidet Konflikte)

---

## 🔧 INTEGRATION SCHRITTE

### Schritt 1: Node ID anpassen
1. Beyond Robotics Node ID von 127 auf 25 ändern
2. Firmware neu kompilieren und uploaden
3. Eindeutige Node IDs sicherstellen

### Schritt 2: Hardware verbinden
1. CAN-Kabel zwischen beiden Geräten
2. Terminierung prüfen
3. Stromversorgung sicherstellen

### Schritt 3: Kommunikation testen
1. CAN-Traffic mit Cangaroo überwachen
2. Node-Discovery prüfen
3. Message-Austausch verifizieren

### Schritt 4: Funktionalität implementieren
1. Battery-Messages vom Beyond Robotics Board
2. Actuator-Commands vom Orange Cube
3. Status-Messages bidirektional

---

## 📊 ERWARTETE ERGEBNISSE

### Nach erfolgreicher Integration:
- ✅ Beide Nodes sichtbar im CAN-Netzwerk
- ✅ GetNodeInfo Requests/Responses
- ✅ Parameter-Austausch möglich
- ✅ Battery-Info vom Beyond Robotics Board
- ✅ Actuator-Commands vom Orange Cube

### CAN-Messages die zu sehen sein sollten:
```
Node 10 (Orange Cube):
- NodeStatus broadcasts
- GetNodeInfo responses
- Actuator commands

Node 25 (Beyond Robotics):
- NodeStatus broadcasts  
- GetNodeInfo responses
- Battery info broadcasts
- Parameter responses
```

---

## 🛠️ TROUBLESHOOTING

### Keine CAN-Kommunikation:
1. **Hardware prüfen**: Verkabelung, Terminierung
2. **Bitrate prüfen**: Beide auf 1 Mbps
3. **Node IDs prüfen**: Keine Duplikate
4. **Power prüfen**: Stabile Versorgung

### Partial Communication:
1. **Timing prüfen**: Message-Raten anpassen
2. **Buffer prüfen**: CAN-Buffer-Größen
3. **Interference prüfen**: Kabel-Qualität

---

## 🎯 NÄCHSTE SCHRITTE

1. **Node ID anpassen** (127 → 25)
2. **Hardware verbinden**
3. **CAN-Traffic überwachen**
4. **Integration testen**
5. **Anwendung entwickeln**

Bereit für die Implementierung! 🚀

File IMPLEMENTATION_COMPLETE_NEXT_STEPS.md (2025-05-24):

# ✅ Beyond Robotics Implementation Complete!
## Ready to Flash Bootloader and Test Serial Communication

### 🎯 CURRENT STATUS
- ✅ Official Arduino-DroneCAN v1.2 project downloaded
- ✅ Working project setup in `beyond_robotics_working/`
- ✅ VSCode workspace created
- ✅ Helper scripts generated
- ✅ All files verified and ready

---

## 📋 NEXT STEPS (In Order)

### Step 1: Download STM32CubeProgrammer
**Download from ST website:**
```
https://www.st.com/en/development-tools/stm32cubeprog.html
```
- Free registration required
- Install with default settings
- Ensure ST-LINK drivers included

### Step 2: Flash AP Bootloader
**Run the guide script:**
```bash
flash_bootloader_guide.bat
```

**Manual process:**
1. Open STM32CubeProgrammer
2. Select "ST-LINK" connection
3. Click "Connect" (verify STM32L431 detected)
4. Go to "Erasing & Programming" tab
5. Browse to: `beyond_robotics_working/AP_Bootloader.bin`
6. Set start address: `0x8000000`
7. Click "Start Programming"
8. Verify successful flash

**Expected result:** Node boots in maintenance mode on CAN bus

### Step 3: Upload Official Firmware
**Run the upload script:**
```bash
upload_firmware.bat
```

**Manual process:**
```bash
cd beyond_robotics_working
pio run --target upload
```

**Expected result:** Firmware uploads successfully via ST-LINK

### Step 4: Test Serial Communication
**Run the monitor script:**
```bash
monitor_serial.bat
```

**Manual process:**
```bash
cd beyond_robotics_working
pio device monitor --port COM8 --baud 115200
```

**Expected output:**
- DroneCAN initialization messages
- Parameter values (PARM_1 = 69, etc.)
- Battery info messages every 100ms
- CPU temperature readings

### Step 5: Open in VSCode
**Open the workspace:**
```bash
beyond_robotics_workspace.code-workspace
```

**Verify in VSCode:**
- PlatformIO extension loaded
- Project structure visible
- Board configuration: BRMicroNode
- Ready for customization

---

## 🔧 HARDWARE VERIFICATION CHECKLIST

Before starting, verify:
- ✅ ST-LINK V3 connected to PC via USB
- ✅ **Use provided cable** between ST-LINK and dev board (per support)
- ✅ SW1 in position "1" (STLINK enabled)
- ✅ Dev board powered (LED visible)
- ✅ COM8 appears in Device Manager

---

## 📊 EXPECTED RESULTS

### After Bootloader Flash:
- ✅ STM32CubeProgrammer reports success
- ✅ Node resets and boots properly
- ✅ Node appears in maintenance mode on CAN bus

### After Firmware Upload:
- ✅ PlatformIO reports successful upload
- ✅ Serial communication works on COM8
- ✅ DroneCAN messages transmitting

### Serial Monitor Output:
```
PARM_1 value: 69
[DroneCAN initialization messages]
[Battery info messages every 100ms]
[CPU temperature readings]
```

---

## 🎯 KEY DIFFERENCES FROM CUSTOM CONFIG

### What Was Wrong:
- ❌ Used `nucleo_l432kc` board (wrong pin mapping)
- ❌ Serial2 not configured for ST-LINK
- ❌ Missing bootloader support
- ❌ No custom variant for Beyond Robotics hardware

### What's Fixed:
- ✅ Uses `BRMicroNode` board (correct pin mapping)
- ✅ Serial uses PA2/PA3 → ST-LINK connection
- ✅ Includes `app_setup()` for bootloader
- ✅ Custom variant with proper hardware definitions

---

## 🚀 CUSTOMIZATION AFTER SUCCESS

Once serial communication works:

### 1. Modify main.cpp for Your Application
```cpp
// In beyond_robotics_working/src/main.cpp
// Customize DroneCAN messages for Orange Cube communication
```

### 2. Test with Orange Cube
- Verify DroneCAN node appears in Orange Cube
- Test message reception
- Implement your specific functionality

### 3. Integration with Existing Setup
- Use working configuration as reference
- Port your application logic to official framework
- Maintain bootloader compatibility

---

## 📞 SUPPORT CONTACTS

If you encounter issues:
- **Beyond Robotics**: admin@beyondrobotix.com
- **Documentation**: https://beyond-robotix.gitbook.io/docs/
- **GitHub**: https://github.com/BeyondRobotix/Arduino-DroneCAN/discussions

---

## ✨ SUCCESS CRITERIA

You'll know it's working when:
- ✅ STM32CubeProgrammer successfully flashes bootloader
- ✅ PlatformIO uploads firmware without errors
- ✅ Serial monitor shows DroneCAN messages on COM8
- ✅ Node communicates with Orange Cube via CAN

**Ready to proceed with Beyond Robotics official solution!**

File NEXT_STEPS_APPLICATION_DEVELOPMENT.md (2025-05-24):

# 🚀 CAN Integration Erfolgreich - Anwendungsentwicklung
## Beyond Robotics ↔ Orange Cube DroneCAN Kommunikation

### ✅ **ERFOLGREICHE INTEGRATION BESTÄTIGT**

**Hardware:**
- ✅ Beyond Robotics Dev Board: Node ID 25, DroneCAN aktiv
- ✅ Orange Cube: Node ID 10, DroneCAN aktiv  
- ✅ CAN-Bus: 1 Mbps, bidirektionale Kommunikation

**Software:**
- ✅ Serial-Kommunikation: COM8 funktioniert perfekt
- ✅ DroneCAN-Messages: Battery-Info alle 10s
- ✅ Node Discovery: GetNodeInfo Requests/Responses
- ✅ Message-Transfer: Stabile Übertragung

---

## 🎯 **ANWENDUNGSENTWICKLUNG - NÄCHSTE SCHRITTE**

### 1. Erweiterte DroneCAN-Messages
**Aktuell implementiert:**
- Battery-Info (Voltage, Current, Temperature)
- GetNodeInfo Response
- Parameter-System

**Mögliche Erweiterungen:**
- **Actuator Commands**: Servo/Motor-Steuerung vom Orange Cube
- **Sensor Data**: GPS, IMU, Umgebungssensoren
- **Status Messages**: System-Health, Fehler-Codes
- **Custom Messages**: Anwendungsspezifische Daten

### 2. Orange Cube Integration
**Aktuell:**
- Orange Cube erkennt Beyond Robotics Node
- Regelmäßige GetNodeInfo Requests

**Erweiterte Integration:**
- **ESC Control**: Orange Cube steuert Motoren über Beyond Robotics
- **Sensor Fusion**: Beyond Robotics Sensoren in Orange Cube Navigation
- **Redundancy**: Backup-Systeme über DroneCAN
- **Telemetry**: Erweiterte Datenübertragung

### 3. Praktische Anwendungen
**UGV (Unmanned Ground Vehicle):**
- Motor-Controller über DroneCAN
- Sensor-Arrays (Lidar, Kameras, etc.)
- Battery-Management-System
- Emergency-Stop-System

**Robotik-Anwendungen:**
- Distributed Control Systems
- Sensor-Netzwerke
- Actuator-Arrays
- Real-time Communication

---

## 🔧 **ENTWICKLUNGSOPTIONEN**

### Option A: Motor-Controller implementieren
```cpp
// In main.cpp - ESC/Motor Control Messages empfangen
void handle_esc_command(CanardRxTransfer* transfer) {
    // Orange Cube → Beyond Robotics Motor Commands
    // PWM/Servo-Ausgänge steuern
}
```

### Option B: Sensor-Data senden
```cpp
// GPS, IMU, oder andere Sensoren
void send_sensor_data() {
    // Beyond Robotics → Orange Cube Sensor-Daten
    // Navigation/Positioning unterstützen
}
```

### Option C: Custom Application Protocol
```cpp
// Anwendungsspezifische Messages
void send_custom_data() {
    // Eigene Message-Types definieren
    // Spezielle Anwendungslogik
}
```

### Option D: Parameter-System erweitern
```cpp
// Mehr konfigurierbare Parameter
std::vector<DroneCAN::parameter> custom_parameters = {
    { "MOTOR_SPEED", UAVCAN_PROTOCOL_PARAM_VALUE_REAL_VALUE, 0.0f, 0.0f, 100.0f },
    { "SENSOR_RATE", UAVCAN_PROTOCOL_PARAM_VALUE_INTEGER_VALUE, 10, 1, 100 },
    // ... weitere Parameter
};
```

---

## 🛠️ **ENTWICKLUNGSUMGEBUNG**

### Verfügbare Tools:
- ✅ **VSCode + PlatformIO**: Firmware-Entwicklung
- ✅ **STM32CubeProgrammer**: Bootloader/Firmware-Flash
- ✅ **Serial Monitor**: Debug-Output
- ✅ **Cangaroo**: CAN-Bus-Analyse (optional)
- ✅ **MAVProxy**: Orange Cube Konfiguration

### Projekt-Struktur:
```
beyond_robotics_working/
├── src/main.cpp              # Hauptanwendung (anpassbar)
├── lib/ArduinoDroneCAN/      # DroneCAN-Library
├── boards/BRMicroNode.json   # Hardware-Definition
├── variants/BRMicroNode/     # Pin-Mapping
└── platformio.ini            # Build-Konfiguration
```

---

## 🎯 **EMPFOHLENER NÄCHSTER SCHRITT**

### Motor-Controller Implementation
**Warum:** Praktische UGV-Anwendung, direkt testbar

**Schritte:**
1. **ESC-Messages** vom Orange Cube empfangen
2. **PWM-Ausgänge** am Beyond Robotics Board konfigurieren
3. **Motor-Control** implementieren
4. **Feedback-System** für Status-Rückmeldung

**Erwartetes Ergebnis:**
- Orange Cube sendet Throttle-Commands
- Beyond Robotics Board steuert Motoren
- Bidirektionale Status-Kommunikation
- Vollständiges UGV-Control-System

---

## 📞 **SUPPORT & DOKUMENTATION**

### Beyond Robotics:
- **Support**: admin@beyondrobotix.com
- **Docs**: https://beyond-robotix.gitbook.io/docs/
- **GitHub**: https://github.com/BeyondRobotix/Arduino-DroneCAN

### DroneCAN Protocol:
- **Specification**: https://dronecan.github.io/
- **Message Types**: Standard DroneCAN Messages
- **Custom Messages**: Eigene Message-Definitionen

---

## ✨ **ERFOLG ZUSAMMENFASSUNG**

Du hast erfolgreich:
- ✅ **Serial-Kommunikationsproblem** gelöst (Beyond Robotics Support-Lösung)
- ✅ **DroneCAN-Kommunikation** implementiert
- ✅ **CAN-Bus Integration** zwischen Orange Cube und Beyond Robotics
- ✅ **Bidirektionale Kommunikation** etabliert
- ✅ **Solide Entwicklungsbasis** geschaffen

**Bereit für die nächste Entwicklungsphase!** 🚀

Welche Anwendung möchtest du als nächstes implementieren?

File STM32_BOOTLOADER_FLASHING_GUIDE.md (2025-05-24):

# STM32 Bootloader Flashing Guide
## Beyond Robotics AP Bootloader Installation

### OVERVIEW
This guide walks through flashing the AP_Bootloader.bin to your Beyond Robotics Dev Board with STM32L431 Micro Node, as recommended by Beyond Robotics support.

---

## PREREQUISITES

### Hardware Setup
- ✅ Beyond Robotics Node Development Board with STM32L431 Micro Node
- ✅ ST-LINK V3 MINI (blue dongle) 
- ✅ **Use provided cable** between ST-LINK and dev board (per support response)
- ✅ SW1 switch in position "1" (STLINK enabled)

### Software Requirements
1. **STM32CubeProgrammer** - Download from ST website
2. **AP_Bootloader.bin** - From Beyond Robotics v1.2 release

---

## STEP 1: DOWNLOAD STM32CUBEPROGRAMMER

### Download Link
```
https://www.st.com/en/development-tools/stm32cubeprog.html
```

### Installation Notes
- Free registration with ST required
- Download latest version (2.16.0 or newer)
- Install with default settings
- Ensure ST-LINK drivers are included

---

## STEP 2: PREPARE BOOTLOADER FILE

### File Location
After running the download script, the bootloader will be at:
```
beyond_robotics_official/AP_Bootloader.bin
```

### File Verification
- **File name**: AP_Bootloader.bin
- **Target address**: 0x8000000
- **Purpose**: Enables firmware updates over CAN

---

## STEP 3: CONNECT HARDWARE

### Connection Checklist
1. ✅ ST-LINK V3 connected to PC via USB
2. ✅ **Use provided cable** between ST-LINK and STLINK header on dev board
3. ✅ SW1 switch in position "1" (STLINK enabled, USB disabled)
4. ✅ Dev board powered (LED should be visible)

### Verify Connection
- ST-LINK should appear in Windows Device Manager
- Should show as "ST-Link Debug" and "USB Serial Device (COM8)"

---

## STEP 4: FLASH BOOTLOADER

### Launch STM32CubeProgrammer
1. Open STM32CubeProgrammer application
2. Select "ST-LINK" connection type
3. Click "Connect" to establish connection with STM32L431

### Flash Process
1. **Select File**: Browse to `AP_Bootloader.bin`
2. **Start Address**: Enter `0x8000000`
3. **Verify Settings**:
   - File path: `beyond_robotics_official/AP_Bootloader.bin`
   - Start address: `0x8000000`
   - Connection: ST-LINK
4. **Flash**: Click "Start Programming"

### Expected Output
```
Connecting to target...
Connection established
Erasing memory...
Programming...
Verifying...
Programming completed successfully
```

---

## STEP 5: VERIFY BOOTLOADER

### Boot Verification
1. **Reset the board** (press reset button or power cycle)
2. **Check LED behavior** - should indicate bootloader is running
3. **CAN Bus Check** - node should appear in maintenance mode

### Maintenance Mode
- Node will show on CAN bus as in maintenance mode
- This indicates bootloader is working correctly
- Ready for firmware upload via PlatformIO

---

## STEP 6: NEXT STEPS

### After Successful Bootloader Flash
1. ✅ Bootloader installed and verified
2. ✅ Node boots in maintenance mode
3. ✅ Ready for Arduino-DroneCAN firmware upload

### Proceed to Firmware Upload
1. Open extracted Arduino-DroneCAN project in VSCode/PlatformIO
2. Press "Upload" in PlatformIO
3. Firmware will be uploaded over ST-LINK
4. Serial communication should work on COM8

---

## TROUBLESHOOTING

### Connection Issues
**Problem**: Cannot connect to STM32L431
**Solutions**:
- Verify ST-LINK drivers installed
- Check cable connections (use provided cable)
- Ensure SW1 in position "1"
- Try different USB port

### Programming Errors
**Problem**: Programming failed
**Solutions**:
- Verify start address is exactly `0x8000000`
- Check file path to AP_Bootloader.bin
- Ensure target is not write-protected
- Try erasing chip first

### Verification Issues
**Problem**: Node doesn't boot in maintenance mode
**Solutions**:
- Verify bootloader was programmed correctly
- Check CAN bus connections
- Reset board after programming
- Verify LED behavior indicates boot

---

## SUPPORT CONTACT

If you encounter issues during bootloader flashing:
- **Beyond Robotics Support**: admin@beyondrobotix.com
- **Documentation**: https://beyond-robotix.gitbook.io/docs/
- **GitHub Discussions**: https://github.com/BeyondRobotix/Arduino-DroneCAN/discussions

---

## SUCCESS CRITERIA

✅ **Bootloader Successfully Installed When**:
- STM32CubeProgrammer reports successful programming
- Board resets and boots properly
- Node appears in maintenance mode on CAN bus
- Ready for firmware upload via PlatformIO

After successful bootloader installation, proceed to upload the official Arduino-DroneCAN firmware!

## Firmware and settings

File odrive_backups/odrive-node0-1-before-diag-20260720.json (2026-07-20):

{"axis0": {"config": {"can_heartbeat_rate_ms": 100, "can_node_id_extended": false, "can_node_id": 0, "dir_gpio_pin": 2, "enable_step_dir": false, "enable_watchdog": false, "startup_closed_loop_control": false, "startup_encoder_index_search": false, "startup_encoder_offset_calibration": false, "startup_homing": false, "startup_motor_calibration": false, "startup_sensorless_control": false, "step_dir_always_on": false, "step_gpio_pin": 1, "turns_per_step": 0.0009765625, "watchdog_timeout": 0.0, "calibration_lockin": {"accel": 20.0, "current": 10.0, "ramp_distance": 3.1415927410125732, "ramp_time": 0.4000000059604645, "vel": 40.0}, "general_lockin": {"accel": 20.0, "current": 10.0, "finish_distance": 100.0, "finish_on_distance": false, "finish_on_enc_idx": false, "finish_on_vel": false, "ramp_distance": 3.1415927410125732, "ramp_time": 0.4000000059604645, "vel": 40.0}, "sensorless_ramp": {"accel": 50.0, "current": 10.0, "finish_distance": 10.0, "finish_on_distance": true, "finish_on_enc_idx": false, "finish_on_vel": true, "ramp_distance": 10.0, "ramp_time": 1.0, "vel": 30.0}}, "controller": {"config": {"axis_to_mirror": 255, "circular_setpoint_range": 1.0, "circular_setpoints": false, "control_mode": 2, "enable_current_mode_vel_limit": true, "enable_gain_scheduling": false, "enable_overspeed_error": true, "enable_vel_limit": true, "gain_scheduling_width": 10.0, "homing_speed": 0.25, "inertia": 0.0, "input_filter_bandwidth": 2.0, "input_mode": 1, "load_encoder_axis": 0, "mirror_ratio": 1.0, "pos_gain": 20.0, "torque_ramp_rate": 0.009999999776482582, "vel_gain": 0.004999999888241291, "vel_integrator_gain": 0.029999999329447746, "vel_limit": 120.0, "vel_limit_tolerance": 1.2000000476837158, "vel_ramp_rate": 1.0, "anticogging": {"anticogging_enabled": true, "calib_anticogging": false, "calib_pos_threshold": 1.0, "calib_vel_threshold": 1.0, "cogging_ratio": 1.0, "index": 0, "pre_calibrated": false}}}, "encoder": {"config": {"abs_spi_cs_gpio_pin": 1, "bandwidth": 100.0, "calib_range": 0.05000000074505806, "calib_scan_distance": 150.0, "calib_scan_omega": 6.2829999923706055, "cpr": 42, "enable_phase_interpolation": true, "find_idx_on_lockin_only": false, "idx_search_unidirectional": false, "ignore_illegal_hall_state": false, "mode": 0, "offset_float": 0.0, "offset": 0, "pre_calibrated": false, "sincos_gpio_pin_cos": 4, "sincos_gpio_pin_sin": 3, "use_index": false, "zero_count_on_find_idx": true}}, "fet_thermistor": {"config": {"enabled": true, "temp_limit_lower": 100.0, "temp_limit_upper": 120.0}}, "max_endstop": {"config": {"debounce_ms": 50, "enabled": false, "gpio_num": 0, "is_active_high": false, "offset": 0.0, "pullup": true}}, "min_endstop": {"config": {"debounce_ms": 50, "enabled": false, "gpio_num": 0, "is_active_high": false, "offset": 0.0, "pullup": true}}, "motor": {"config": {"acim_autoflux_attack_gain": 10.0, "acim_autoflux_decay_gain": 1.0, "acim_autoflux_enable": false, "acim_autoflux_min_Id": 10.0, "acim_gain_min_flux": 10.0, "acim_slip_velocity": 14.706000328063965, "calibration_current": 5.0, "current_control_bandwidth": 100.0, "current_lim_margin": 8.0, "current_lim": 30.0, "direction": 1, "inverter_temp_limit_lower": 100.0, "inverter_temp_limit_upper": 120.0, "motor_type": 0, "phase_inductance": 1.4818512681813445e-05, "phase_resistance": 0.05119955539703369, "pole_pairs": 7, "pre_calibrated": true, "requested_current_range": 60.0, "resistance_calib_max_voltage": 4.0, "torque_constant": 0.03999999910593033, "torque_lim": Infinity}}, "motor_thermistor": {"config": {"enabled": false, "gpio_pin": 4, "poly_coefficient_0": 0.0, "poly_coefficient_1": 0.0, "poly_coefficient_2": 0.0, "poly_coefficient_3": 0.0, "temp_limit_lower": 100.0, "temp_limit_upper": 120.0}}, "sensorless_estimator": {"config": {"observer_gain": 1000.0, "pll_bandwidth": 1000.0, "pm_flux_linkage": 0.002386000007390976}}, "trap_traj": {"config": {"accel_limit": 0.5, "decel_limit": 0.5, "vel_limit": 2.0}}}, "axis1": {"config": {"can_heartbeat_rate_ms": 100, "can_node_id_extended": false, "can_node_id": 1, "dir_gpio_pin": 8, "enable_step_dir": false, "enable_watchdog": false, "startup_closed_loop_control": false, "startup_encoder_index_search": false, "startup_encoder_offset_calibration": false, "startup_homing": false, "startup_motor_calibration": false, "startup_sensorless_control": false, "step_dir_always_on": false, "step_gpio_pin": 7, "turns_per_step": 0.0009765625, "watchdog_timeout": 0.0, "calibration_lockin": {"accel": 20.0, "current": 10.0, "ramp_distance": 3.1415927410125732, "ramp_time": 0.4000000059604645, "vel": 40.0}, "general_lockin": {"accel": 20.0, "current": 10.0, "finish_distance": 100.0, "finish_on_distance": false, "finish_on_enc_idx": false, "finish_on_vel": false, "ramp_distance": 3.1415927410125732, "ramp_time": 0.4000000059604645, "vel": 40.0}, "sensorless_ramp": {"accel": 50.0, "current": 10.0, "finish_distance": 10.0, "finish_on_distance": true, "finish_on_enc_idx": false, "finish_on_vel": true, "ramp_distance": 10.0, "ramp_time": 1.0, "vel": 30.0}}, "controller": {"config": {"axis_to_mirror": 255, "circular_setpoint_range": 1.0, "circular_setpoints": false, "control_mode": 2, "enable_current_mode_vel_limit": true, "enable_gain_scheduling": false, "enable_overspeed_error": true, "enable_vel_limit": true, "gain_scheduling_width": 10.0, "homing_speed": 0.25, "inertia": 0.0, "input_filter_bandwidth": 2.0, "input_mode": 1, "load_encoder_axis": 1, "mirror_ratio": 1.0, "pos_gain": 20.0, "torque_ramp_rate": 0.009999999776482582, "vel_gain": 0.004999999888241291, "vel_integrator_gain": 0.029999999329447746, "vel_limit": 120.0, "vel_limit_tolerance": 1.2000000476837158, "vel_ramp_rate": 1.0, "anticogging": {"anticogging_enabled": true, "calib_anticogging": false, "calib_pos_threshold": 1.0, "calib_vel_threshold": 1.0, "cogging_ratio": 1.0, "index": 0, "pre_calibrated": false}}}, "encoder": {"config": {"abs_spi_cs_gpio_pin": 1, "bandwidth": 100.0, "calib_range": 0.05000000074505806, "calib_scan_distance": 150.0, "calib_scan_omega": 6.2829999923706055, "cpr": 42, "enable_phase_interpolation": true, "find_idx_on_lockin_only": false, "idx_search_unidirectional": false, "ignore_illegal_hall_state": false, "mode": 0, "offset_float": 0.0, "offset": 0, "pre_calibrated": false, "sincos_gpio_pin_cos": 4, "sincos_gpio_pin_sin": 3, "use_index": false, "zero_count_on_find_idx": true}}, "fet_thermistor": {"config": {"enabled": true, "temp_limit_lower": 100.0, "temp_limit_upper": 120.0}}, "max_endstop": {"config": {"debounce_ms": 50, "enabled": false, "gpio_num": 0, "is_active_high": false, "offset": 0.0, "pullup": true}}, "min_endstop": {"config": {"debounce_ms": 50, "enabled": false, "gpio_num": 0, "is_active_high": false, "offset": 0.0, "pullup": true}}, "motor": {"config": {"acim_autoflux_attack_gain": 10.0, "acim_autoflux_decay_gain": 1.0, "acim_autoflux_enable": false, "acim_autoflux_min_Id": 10.0, "acim_gain_min_flux": 10.0, "acim_slip_velocity": 14.706000328063965, "calibration_current": 5.0, "current_control_bandwidth": 100.0, "current_lim_margin": 8.0, "current_lim": 30.0, "direction": 1, "inverter_temp_limit_lower": 100.0, "inverter_temp_limit_upper": 120.0, "motor_type": 0, "phase_inductance": 1.473599058954278e-05, "phase_resistance": 0.053092747926712036, "pole_pairs": 7, "pre_calibrated": true, "requested_current_range": 60.0, "resistance_calib_max_voltage": 4.0, "torque_constant": 0.03999999910593033, "torque_lim": Infinity}}, "motor_thermistor": {"config": {"enabled": false, "gpio_pin": 4, "poly_coefficient_0": 0.0, "poly_coefficient_1": 0.0, "poly_coefficient_2": 0.0, "poly_coefficient_3": 0.0, "temp_limit_lower": 100.0, "temp_limit_upper": 120.0}}, "sensorless_estimator": {"config": {"observer_gain": 1000.0, "pll_bandwidth": 1000.0, "pm_flux_linkage": 0.002386000007390976}}, "trap_traj": {"config": {"accel_limit": 0.5, "decel_limit": 0.5, "vel_limit": 2.0}}}, "can": {"config": {"baud_rate": 250000, "protocol": 0}}, "config": {"brake_resistance": 0.0, "dc_bus_overvoltage_ramp_end": 59.92000198364258, "dc_bus_overvoltage_ramp_start": 59.92000198364258, "dc_bus_overvoltage_trip_level": 32.0, "dc_bus_undervoltage_trip_level": 20.0, "dc_max_negative_current": -2.0, "dc_max_positive_current": 40.0, "enable_ascii_protocol_on_usb": true, "enable_dc_bus_overvoltage_ramp": false, "enable_i2c_instead_of_can": false, "enable_uart": true, "max_regen_current": 0.0, "uart_baudrate": 115200, "gpio1_pwm_mapping": {"endpoint": null, "max": 0.0, "min": 0.0}, "gpio2_pwm_mapping": {"endpoint": null, "max": 0.0, "min": 0.0}, "gpio3_analog_mapping": {"endpoint": null, "max": 0.0, "min": 0.0}, "gpio3_pwm_mapping": {"endpoint": null, "max": 0.0, "min": 0.0}, "gpio4_analog_mapping": {"endpoint": null, "max": 0.0, "min": 0.0}, "gpio4_pwm_mapping": {"endpoint": null, "max": 0.0, "min": 0.0}}}

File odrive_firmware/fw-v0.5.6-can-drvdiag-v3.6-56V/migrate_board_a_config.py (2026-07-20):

#!/usr/bin/env python3
"""Apply and verify the known-safe UGV configuration for ODrive Board A.

This script is intentionally specific to the v3.6-56V board with USB serial
0x386132523135. It never requests a motor state other than IDLE.
"""

import argparse
import math
import sys

import odrive


EXPECTED_SERIAL = 0x386132523135
EXPECTED_FW = (0, 5, 6)
EXPECTED_HW = (3, 6, 56)


def connect():
    print("Waiting for ODrive Board A over USB ...", flush=True)
    board = odrive.find_any(timeout=30)
    serial = int(board.serial_number)
    firmware = (
        int(board.fw_version_major),
        int(board.fw_version_minor),
        int(board.fw_version_revision),
    )
    hardware = (
        int(board.hw_version_major),
        int(board.hw_version_minor),
        int(board.hw_version_variant),
    )
    print(
        f"Found serial=0x{serial:X}, firmware={firmware}, hardware={hardware}",
        flush=True,
    )
    if serial != EXPECTED_SERIAL:
        raise RuntimeError(
            f"Refusing wrong board: expected 0x{EXPECTED_SERIAL:X}, got 0x{serial:X}"
        )
    if firmware != EXPECTED_FW:
        raise RuntimeError(f"Expected firmware {EXPECTED_FW}, got {firmware}")
    if hardware != EXPECTED_HW:
        raise RuntimeError(f"Expected hardware {EXPECTED_HW}, got {hardware}")
    return board


def require_idle(board):
    for index, axis in enumerate((board.axis0, board.axis1)):
        axis.controller.input_vel = 0.0
        axis.requested_state = 1  # AXIS_STATE_IDLE
        if int(axis.current_state) != 1:
            raise RuntimeError(f"axis{index} is not IDLE: state={int(axis.current_state)}")


def set_lockin(lockin, *, current, ramp_time, ramp_distance, accel, vel,
               finish_distance=None, finish_on_vel=None,
               finish_on_distance=None, finish_on_enc_idx=None):
    lockin.current = current
    lockin.ramp_time = ramp_time
    lockin.ramp_distance = ramp_distance
    lockin.accel = accel
    lockin.vel = vel
    if finish_distance is not None:
        lockin.finish_distance = finish_distance
    if finish_on_vel is not None:
        lockin.finish_on_vel = finish_on_vel
    if finish_on_distance is not None:
        lockin.finish_on_distance = finish_on_distance
    if finish_on_enc_idx is not None:
        lockin.finish_on_enc_idx = finish_on_enc_idx


def configure_axis(axis, node_id, phase_resistance, phase_inductance):
    cfg = axis.config

    # No autonomous movement at boot.
    cfg.startup_motor_calibration = False
    cfg.startup_encoder_index_search = False
    cfg.startup_encoder_offset_calibration = False
    cfg.startup_closed_loop_control = False
    cfg.startup_homing = False
    cfg.enable_step_dir = False
    cfg.step_dir_always_on = False
    # Set_Input_Vel is refreshed by the Raspberry Pi every 100 ms. If CAN or
    # the host dies, the axis must disarm locally because an IDLE frame can no
    # longer reach the board.
    cfg.watchdog_timeout = 1.0
    cfg.enable_watchdog = True
    cfg.enable_sensorless_mode = True

    cfg.can.node_id = node_id
    cfg.can.is_extended = False
    cfg.can.heartbeat_rate_ms = 100
    cfg.can.encoder_rate_ms = 0
    cfg.can.motor_error_rate_ms = 0
    cfg.can.encoder_error_rate_ms = 0
    cfg.can.controller_error_rate_ms = 0
    cfg.can.sensorless_error_rate_ms = 0
    cfg.can.encoder_count_rate_ms = 0
    cfg.can.iq_rate_ms = 0
    cfg.can.sensorless_rate_ms = 0
    cfg.can.bus_vi_rate_ms = 0

    set_lockin(
        cfg.calibration_lockin,
        current=10.0,
        ramp_time=0.4,
        ramp_distance=math.pi,
        accel=20.0,
        vel=40.0,
    )
    set_lockin(
        cfg.general_lockin,
        current=10.0,
        ramp_time=0.4,
        ramp_distance=math.pi,
        accel=20.0,
        vel=40.0,
        finish_distance=100.0,
        finish_on_vel=False,
        finish_on_distance=False,
        finish_on_enc_idx=False,
    )
    set_lockin(
        cfg.sensorless_ramp,
        current=10.0,
        ramp_time=1.0,
        ramp_distance=10.0,
        accel=50.0,
        vel=30.0,
        finish_distance=10.0,
        finish_on_vel=True,
        finish_on_distance=True,
        finish_on_enc_idx=False,
    )

    motor = axis.motor.config
    # Set calibration results before marking the motor pre-calibrated.
    motor.pre_calibrated = False
    motor.motor_type = 0
    motor.pole_pairs = 7
    motor.calibration_current = 5.0
    motor.resistance_calib_max_voltage = 4.0
    motor.phase_resistance = phase_resistance
    motor.phase_inductance = phase_inductance
    motor.torque_constant = 0.04
    motor.current_lim = 30.0
    motor.current_lim_margin = 8.0
    motor.requested_current_range = 60.0
    motor.current_control_bandwidth = 100.0
    motor.inverter_temp_limit_lower = 100.0
    motor.inverter_temp_limit_upper = 120.0
    motor.pre_calibrated = True

    axis.motor.fet_thermistor.config.enabled = True
    axis.motor.fet_thermistor.config.temp_limit_lower = 100.0
    axis.motor.fet_thermistor.config.temp_limit_upper = 120.0
    axis.motor.motor_thermistor.config.enabled = False

    encoder = axis.encoder.config
    encoder.mode = 0
    encoder.use_index = False
    encoder.find_idx_on_lockin_only = False
    encoder.cpr = 42
    encoder.phase_offset = 0
    encoder.phase_offset_float = 0.0
    encoder.direction = 0
    encoder.pre_calibrated = False
    encoder.enable_phase_interpolation = True
    encoder.bandwidth = 100.0
    encoder.calib_range = 0.05
    encoder.calib_scan_distance = 150.0
    encoder.calib_scan_omega = 6.283
    encoder.ignore_illegal_hall_state = False

    estimator = axis.sensorless_estimator.config
    estimator.observer_gain = 1000.0
    estimator.pll_bandwidth = 1000.0
    estimator.pm_flux_linkage = 0.002386

    controller = axis.controller.config
    controller.control_mode = 2
    controller.input_mode = 1
    controller.enable_vel_limit = True
    controller.enable_torque_mode_vel_limit = True
    controller.enable_gain_scheduling = False
    controller.enable_overspeed_error = True
    controller.pos_gain = 20.0
    controller.vel_gain = 0.005
    controller.vel_integrator_gain = 0.03
    controller.vel_limit = 120.0
    controller.vel_limit_tolerance = 1.2
    controller.vel_ramp_rate = 1.0
    controller.torque_ramp_rate = 0.01
    controller.input_filter_bandwidth = 2.0
    controller.inertia = 0.0


def apply_configuration(board):
    require_idle(board)

    board.config.enable_can_a = True
    board.config.enable_i2c_a = False
    board.config.enable_uart_a = True
    board.config.uart_a_baudrate = 115200
    board.can.config.baud_rate = 250000
    # fw-v0.5.6 changed this from the legacy enum value 0 to a bit flag.
    board.can.config.protocol = 1  # PROTOCOL_SIMPLE

    board.config.enable_brake_resistor = False
    board.config.brake_resistance = 0.0
    board.config.dc_bus_overvoltage_trip_level = 32.0
    board.config.dc_bus_undervoltage_trip_level = 20.0
    board.config.enable_dc_bus_overvoltage_ramp = False
    board.config.max_regen_current = 0.0
    board.config.dc_max_negative_current = -2.0
    board.config.dc_max_positive_current = 40.0

    configure_axis(board.axis0, 0, 0.05119955539703369, 1.4818512681813445e-05)
    configure_axis(board.axis1, 1, 0.053092747926712036, 1.473599058954278e-05)

    require_idle(board)
    verify_configuration(board, require_clean_errors=False)
    print("Configuration is valid in RAM. Saving and rebooting Board A ...", flush=True)
    success = board.save_configuration()
    if success is False:
        raise RuntimeError("ODrive rejected save_configuration()")


def close(actual, expected, tolerance=1e-5):
    return math.isclose(float(actual), float(expected), rel_tol=tolerance, abs_tol=tolerance)


def verify_configuration(board, require_clean_errors=True):
    require_idle(board)
    checks = [
        (bool(board.config.enable_can_a), True, "CAN enabled"),
        (bool(board.config.enable_i2c_a), False, "I2C disabled"),
        (int(board.can.config.baud_rate), 250000, "CAN bitrate"),
        (int(board.can.config.protocol), 1, "CANSimple protocol"),
        (bool(board.config.enable_brake_resistor), False, "brake resistor disabled"),
    ]
    failures = []
    for actual, expected, label in checks:
        if actual != expected:
            failures.append(f"{label}: expected {expected!r}, got {actual!r}")

    expected_phases = (
        (0, 0.05119955539703369, 1.4818512681813445e-05),
        (1, 0.053092747926712036, 1.473599058954278e-05),
    )
    for index, (node_id, resistance, inductance) in enumerate(expected_phases):
        axis = (board.axis0, board.axis1)[index]
        axis_checks = [
            (int(axis.current_state) == 1, f"axis{index} IDLE"),
            (int(axis.config.can.node_id) == node_id, f"axis{index} node ID"),
            (int(axis.config.can.heartbeat_rate_ms) == 100, f"axis{index} heartbeat"),
            (bool(axis.config.enable_watchdog), f"axis{index} watchdog enabled"),
            (close(axis.config.watchdog_timeout, 1.0), f"axis{index} watchdog timeout"),
            (bool(axis.config.enable_sensorless_mode), f"axis{index} sensorless enabled"),
            (not bool(axis.config.startup_motor_calibration), f"axis{index} no startup calibration"),
            (not bool(axis.config.startup_closed_loop_control), f"axis{index} no startup closed loop"),
            (bool(axis.motor.config.pre_calibrated), f"axis{index} motor pre-calibrated"),
            (close(axis.motor.config.phase_resistance, resistance), f"axis{index} phase resistance"),
            (close(axis.motor.config.phase_inductance, inductance), f"axis{index} phase inductance"),
            (close(axis.motor.config.current_lim, 30.0), f"axis{index} current limit"),
            (close(axis.controller.config.vel_limit, 120.0), f"axis{index} velocity limit"),
        ]
        if require_clean_errors:
            axis_checks.extend(
                [
                    (int(axis.error) == 0, f"axis{index} axis error=0"),
                    (int(axis.motor.error) == 0, f"axis{index} motor error=0"),
                ]
            )
        failures.extend(label for passed, label in axis_checks if not passed)

    if failures:
        raise RuntimeError("Configuration verification failed:\n  - " + "\n  - ".join(failures))

    print(
        f"Verified: Vbus={float(board.vbus_voltage):.2f} V, CAN=250000, "
        "nodes=0/1, both axes IDLE, sensorless enabled, startup movement disabled",
        flush=True,
    )


def main():
    parser = argparse.ArgumentParser()
    parser.add_argument("mode", choices=("erase", "apply", "verify"))
    args = parser.parse_args()
    board = connect()
    if args.mode == "erase":
        require_idle(board)
        print("Erasing configuration and rebooting to fw-v0.5.6 defaults ...", flush=True)
        board.erase_configuration()
    elif args.mode == "apply":
        apply_configuration(board)
    else:
        verify_configuration(board)


if __name__ == "__main__":
    try:
        main()
    except Exception as exc:
        print(f"ERROR: {exc}", file=sys.stderr, flush=True)
        sys.exit(1)

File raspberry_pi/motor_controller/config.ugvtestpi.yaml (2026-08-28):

# Raspberry Pi teststand profile for ODrive/ODESC mower-deck bring-up over
# direct USB/Fibre links. The CAN bus this profile once used is gone.
# No camera, no pose source, and no GPIO/PWM mower outputs.

pwm:
  enabled: false
  pins:
    left: 19
    right: 18
  frequency: 50
  neutral_value: 1500
  min_value: 1000
  max_value: 2000
  forward_factor: 500.0
  turn_factor: 300.0

ramping:
  enabled: true
  acceleration_rate: 25
  deceleration_rate: 800
  brake_rate: 1500
  update_interval: 0.02

safety:
  pin: 17
  enabled: false
  debounce_time: 0.2
  command_timeout: 2.0
  joystick_timeout: 1.0
  link_watchdog_enabled: false
  link_watchdog_startup_grace_s: 5.0
  link_watchdog_interval_s: 0.1

light:
  enabled: false
  pin: 22

odrive_mower:
  enabled: true
  node_id: 0
  node_ids: [0, 1, 2]
  # Je Achse ein Eintrag {node_id, serial_number, axis}. Die Seriennummern
  # stehen auf den Boards des jeweiligen Teststands und muessen vor dem
  # ersten Lauf hier eingetragen werden - ohne sie findet der Controller
  # keine Achse.
  usb_axes: []
  axis_state: 5
  min_rpm: 500
  max_rpm: 5000
  default_rpm: 500
  ramp_rate_rpm_s: 300
  command_interval_s: 0.1
  coast_delay_s: 0.5
  start_stagger_s: 0.3
  heartbeat_timeout_s: 1.0
  current_monitor_enabled: true
  current_poll_interval_s: 0.1
  current_response_timeout_s: 10.0
  current_startup_grace_s: 2.0
  current_trip_a: 25.0
  current_trip_duration_s: 0.5
  current_critical_trip_a: 29.0
  current_critical_trip_duration_s: 0.1

navigation:
  enabled: false
  watchdog_timeout_s: 1.0
  geofence_radius_m: 50.0
  max_joystick: 0.30
  acceptance_radius_m: 0.25
  slowdown_radius_m: 0.5
  turn_kp: 0.02
  track_lookahead_m: 0.8
  pivot_heading_threshold_deg: 70.0
  goto_divergence_limit_m: 0.75
  goto_divergence_samples: 5
  track_cross_track_limit_m: 1.0
  min_inner_wheel_speed: 0.50

mapping:
  enabled: false
  maps_dir: /home/imperator/ugvtestpi/maps
  min_point_distance_m: 0.25

web:
  enabled: true
  host: 0.0.0.0
  port: 8080
  secret_key: ugvtestpi_teststand
  template_folder: templates
  static_folder: static
  max_speed_percent: 20.0

logging:
  level: INFO
  format: '%(asctime)s - %(name)s - %(levelname)s - %(message)s'
  file: /home/imperator/ugvtestpi/motor_controller.log
  console: true
  file_enabled: false

quiet: false
monitor: true

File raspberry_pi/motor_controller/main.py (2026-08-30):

#!/usr/bin/env python3
"""
Quassel UGV Motor Controller - Main Entry Point
Modulare Architektur mit separaten Komponenten
"""

import argparse
import logging
import os
import signal
import sys
import threading
import time
import yaml
from pathlib import Path

from .config import Config
from .hardware.gpio_controller import GPIOController
from .hardware.pwm_controller import PWMController
from .hardware.odrive_usb_mower import ODriveUSBMowerController
from .hardware.safety_monitor import SafetyMonitor
from .hardware.status_lamp import StatusLamp
from .hardware.voice_announcer import VoiceAnnouncer
from .hardware.battery_monitor import BatteryMonitor
from .communication.network_monitor import NetworkMonitor
from .communication.push_notifier import PushNotifier
from .sensors.local_pose_source import LocalPoseSource
from .sensors.pose_cache import PoseCache
from .control.motor_control import MotorControl
from .control.joystick_handler import JoystickHandler
from .navigation.navigation_controller import NavigationController
from .mapping import MappingRecorder
from .web.web_server import WebServer


class MotorControllerApp:
    """
    Haupt-Anwendung für Motor Controller
    Orchestriert alle Komponenten
    """

    # Wartezeit auf den Maehdeck-Notstopp, bevor der Safety-Watchdog ihn
    # aufgibt und ohne ihn weiterarbeitet.
    MOWER_STOP_JOIN_TIMEOUT_S = 2.0

    def __init__(self, config: Config):
        """
        Initialisiert Motor Controller App
        
        Args:
            config: Config-Instanz
        """
        self.config = config
        self.logger = self._setup_logging()
        
        # Komponenten
        self.gpio: GPIOController = None
        self.pwm: PWMController = None
        self.safety: SafetyMonitor = None
        self.lamp: StatusLamp = None
        self.voice: VoiceAnnouncer = None
        self.pose_cache: PoseCache = None
        self.local_pose: LocalPoseSource = None
        self.odrive_mower: ODriveMowerController = None
        self.battery: BatteryMonitor = None
        self.network: NetworkMonitor = None
        self.motor: MotorControl = None
        self.joystick: JoystickHandler = None
        self.navigation: NavigationController = None
        self.mapping: MappingRecorder = None
        self.web: WebServer = None
        self.notifier: PushNotifier = None
        self._sensor_pause_resume_mode = None
        self._sensor_recovery_started_monotonic = None
        
        # Shutdown-Flag
        self.running = False
        
        # Signal-Handler registrieren
        signal.signal(signal.SIGINT, self._signal_handler)
        signal.signal(signal.SIGTERM, self._signal_handler)
    
    def _setup_logging(self) -> logging.Logger:
        """
        Konfiguriert Logging
        
        Returns:
            Logger-Instanz
        """
        # Root-Logger konfigurieren
        log_level = getattr(logging, self.config.logging.level.upper(), logging.INFO)
        
        handlers = []
        
        # Console-Handler
        if self.config.logging.console:
            console_handler = logging.StreamHandler()
            console_handler.setLevel(log_level)
            console_handler.setFormatter(logging.Formatter(self.config.logging.format))
            handlers.append(console_handler)
        
        # File-Handler
        if self.config.logging.file_enabled:
            try:
                file_handler = logging.FileHandler(self.config.logging.file)
                file_handler.setLevel(log_level)
                file_handler.setFormatter(logging.Formatter(self.config.logging.format))
                handlers.append(file_handler)
            except Exception as e:
                print(f"⚠️ Logging-Datei konnte nicht erstellt werden: {e}")
        
        # Root-Logger konfigurieren
        logging.basicConfig(
            level=log_level,
            format=self.config.logging.format,
            handlers=handlers
        )
        
        return logging.getLogger(__name__)
    
    def _signal_handler(self, signum, frame):
        """Signal-Handler für SIGINT/SIGTERM"""
        self.logger.info(f"Signal {signum} empfangen - Shutdown wird eingeleitet")
        self.shutdown()
    
    def initialize(self):
        """Initialisiert alle Komponenten"""
        self.logger.info("=" * 60)
        self.logger.info("Quassel UGV Motor Controller v2.0")
        self.logger.info("=" * 60)
        
        try:
            # GPIO-Controller (Singleton)
            self.logger.info("Initialisiere GPIO-Controller...")
            self.gpio = GPIOController()

            # Licht-Relais. Laeuft ueber die Lampe statt direkt ueber den
            # GPIO, damit Handbedienung und Signalfolgen sich nicht
            # gegenseitig ueberschreiben.
            self.lamp = StatusLamp(self.config.light, self.gpio, self.logger)
            self.lamp.initialize()

            # Sprachansagen. Sagen dasselbe wie das Licht, nur in Worten -
            # wer davorsteht, muss dafuer nicht hinsehen.
            self.voice = VoiceAnnouncer(self.config.voice, self.logger)
            if self.voice.initialize():
                self.voice.start()

            # PWM-Controller
            self.logger.info("Initialisiere PWM-Controller...")
            self.pwm = PWMController(
                self.config.pwm,
                self.gpio
            )
            
            # Push-Meldungen. Muss vor dem Safety-Monitor stehen, damit dessen
            # allererster Stopp bereits gemeldet werden kann.
            self.notifier = PushNotifier(self.config.notifications)

            # Safety-Monitor
            self.logger.info("Initialisiere Safety-Monitor...")
            self.safety = SafetyMonitor(self.config.safety, self.gpio)
            self.safety.set_notifier(self.notifier)
            
            # Pose-Zwischenspeicher. Er haelt nur die letzte Pose und ihr
            # Alter; wer sie fuellt, steht darunter.
            self.pose_cache = PoseCache()

            self.logger.info("Initialisiere lokale GNSS-Pose...")
            self.local_pose = LocalPoseSource(
                self.config.pose,
                self._on_local_sensor_data,
            )
            self.pose_cache.set_source_status_callback(self.local_pose.get_status)

            if self.config.odrive_mower.enabled:
                self.logger.info("Initialisiere ODrive-Maehdeck ueber USB...")
                self.odrive_mower = ODriveUSBMowerController(
                    self.config.odrive_mower,
                    self.safety,
                )

            # Batterieueberwachung
            self.battery = BatteryMonitor(self.config.battery, self.logger)

            # Netzueberwachung: zeigt an, in welchem WLAN das Fahrzeug haengt
            self.network = NetworkMonitor(self.config.network, self.logger)
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

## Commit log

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2025-06-03 Fix critical STM32L431 watchdog initialization bug
    - Replace broken IWatchdog.begin() with direct HAL IWDG programming
    - Add stabilization delay after app_setup() for hardware stability
    - Restore full DroneCAN ESC command processing and motor control
    - System now stable >30 minutes with complete PA8/PA9 PWM functionality
    Technical details:
    * IWatchdog.begin() caused immediate crashes on STM32L431
    * Direct IWDG register access (0x5555/0xCCCC/0xAAAA) works reliably
    * 32-second watchdog timeout with aggressive feeding prevents resets
    * Full CAN→PWM pipeline: Orange Cube → DroneCAN → Motor Controller → HAL TIM1
    Fixes: Beyond Robotics STM32L431 board compatibility
    Tested: 20+ minutes co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
    [main.cpp]
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2025-10-21 🧹 Clean up Orange Cube components and update documentation
    - Remove all Orange Cube related directories and test scripts
    - Delete tools/orange_cube directory (abandoned due to CAN bug)
    - Remove cleanup_orange_cube.py and test scripts
    - Update main README.md with new RTK-GPS + IMU tech stack
    - Add bug report link: https://github.com/ArduPilot/ardupilot/issues/31212
    - Update raspberry_pi/README.md for sensor hub and controller
    - Remove outdated ESC controller documentation
    - Update tools/README.md for CAN testing only
    - All documentation now in English
    - Focus on Holybro UM982 GPS + ICM-42688-P IMU + Bing Maps web interface
    [mav.parm]
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2025-10-21 feat: Secure NTRIP/RTK credentials with environment variables
    - Move NTRIP credentials from config.py to .env file
    - Add python-dotenv for environment variable management
    - Create .env.example template for new developers
    - Add .gitignore to prevent .env commits
    - Add SECURITY.md with security best practices
    - Add SETUP_NTRIP.md with step-by-step setup guide
    - Update root .gitignore to protect all .env files
    - Implement 12-Factor App config pattern
    Security improvements:
    - Credentials no longer hardcoded in source
    - .env files protected from accidental commits
    - Clear documentation for secure development
    - Template-based setup for new environments
    [config.py, gps_handler.py, gps_ntrip_bridge.py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]
2025-10-21 refactor: Implement robust NMEA parsing and GPGGA transmission for RTK
    Critical improvements based on code review:
    1. Replace manual NMEA parsing with pynmea2
    - Validates checksums automatically
    - Handles all edge cases (empty fields, corrupted data)
    - Prevents crashes from malformed NMEA sentences
    - Properly parses GGA, HDT, and other sentence types
    2. Implement GPGGA transmission to NTRIP server
    - Send position every 10 seconds for VRS (Virtual Reference Station)
    - Without this, NTRIP server cannot calculate optimal corrections
    - Critical for achieving RTK FIXED status
    - Stores last raw GGA sentence for periodic transmission
    3. Improve encapsulation in GPSHandler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
    [gps_handler.py, gps_ntrip_bridge.py, ntrip_client.py]
2025-10-21 refactor: Add robustness improvements for field deployment
    Final polish for production-ready RTK system:
    1. Silent failure detection for GPS reception
    - Add warning when GPGGA transmission fails due to missing GPS data
    - Helps diagnose poor antenna placement or sky visibility issues
    - Logs: 'Wollte GPGGA an NTRIP senden, aber kein gültiger Satz vom GPS verfügbar'
    - Critical for field troubleshooting
    2. Robust position validation in get_bing_maps_url()
    - Check rtk_status instead of just coordinate values
    - Prevents generating maps URLs for (0.0, 0.0) - Equator off Africa coast
    - Only generate URL when status is not 'NO GPS' or empty
    - Add thread-safe lock for concu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
    [gps_handler.py, gps_ntrip_bridge.py]
2025-10-26 Fix: ICM-42688-P IMU driver - correct register addresses and data reading
    - Fixed critical bug: register addresses were incorrect (0x0B -> 0x1D)
    - Corrected 14-byte data block reading: Temp(2) + Accel(6) + Gyro(6)
    - Fixed FS_SEL bits: 0b110 -> 0b011 for ±2g and ±250°/s configuration
    - Removed incorrect axis remapping and fudge factors
    - IMU now correctly reports sensor data in real-time
    - Web interface displays live IMU data with proper scaling
    - Cleaned up all test scripts and debug files
    [config.py]
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2025-11-04 Motor Controller v2.0: Complete refactoring with Socket.IO and GPIO fixes
    - Refactored monolithic 520-line class into 8 modular components
    - Implemented Socket.IO for real-time joystick control
    - Fixed GPIO22/GPIO23 initialization for light and mower relays
    - Added proper API responses with success field
    - Implemented Singleton pattern for GPIO/pigpio management
    - Added thread-safety with locks for all shared resources
    - Implemented timeout watchdog and emergency stop
    - Added YAML configuration support
    - Fully implemented mower PWM control
    - Added proper exception handling and structured logging
    All features tested and working:
    - CAN bus communication with Sensor Hub
    - Real-time joystick co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
    [config.py, gpio_controller.py, main.py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]
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2025-11-06 Fix: Joystick-Steuerung Links/Rechts vertauscht + Service läuft als root für Port 80
    - Motor Control: Vorzeichen für Turn-Faktor vertauscht (Links/Rechts waren vertauscht)
    - Systemd Service: User=root statt nicolay (Port 80 braucht root-Rechte)
    - Systemd Service: Restart=always statt on-failure (startet immer neu, auch nach Reboot)
    - Systemd Service: RestartSec=5 statt 10 (schnellerer Neustart)
    - Problem behoben: 'Permission denied' beim Binden von Port 80 nach Reboot
    [motor_control.py]
2025-11-06 Fix: NTRIP connection now works reliably - RTK FIXED achieved
    - Bridge now starts monitor thread even if initial NTRIP connection fails
    - Added enable() method to NTRIP client for proper reconnect handling
    - Reconnect attempts now start immediately instead of waiting 30 seconds
    - NTRIP status now shows ONLINE in web interface
    - RTK FIXED status achieved with continuous correction data flow
    [gps_ntrip_bridge.py, ntrip_client.py]
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2026-05-08 Heading pipeline: NMEA THS/HDT parsing, dual-GNSS offset, IMU online calibration, Leaflet map
    GPS handler:
    - Parse THS/HDT NMEA sentences for true heading from UM982 dual-antenna baseline
    Vehicle geometry / heading correction:
    - Mast and sensors moved to rear_right in driver-frame (y=+0.255)
    - gnss.heading_offset_deg compensates antenna-baseline vs vehicle-forward axis (currently +90 deg)
    - imu.heading_offset_deg as static fallback offset for IMU yaw
    IMU heading online calibration (Option C):
    - New ImuHeadingOffsetEstimator with circular running mean (atan2 of mean sin/cos)
    - Quality gates: RTK FIXED/FLOAT only, max heading rate 5 deg/s, min 10 samples, 60-sample window
    - Hierarchy on GPS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
    [gps_handler.py, vehicle_geometry.py]
2026-05-09 Autonome Wegpunkt-Navigation: CAN-Pose-Pipeline, Hebelarm-Korrektur, Overshoot-Detector
    Sensor-Hub:
    - Lever-arm-Korrektur in vehicle_geometry.correct_to_vehicle_center: Antennenposition wird via Heading auf Fahrzeugzentrum verschoben
    - _compute_heading_info() priorisiert dual-GNSS-Heading vor IMU-Fallback (heading_source: dual_gnss / imu_fallback)
    - Pose im Telemetrie-Payload und in /api/vehicle/footprint zeigt jetzt Fahrzeugzentrum, nicht Antenne
    Motor-Controller:
    - NavigationController: Wegpunkt-Anfahrt per CAN-Telemetrie-Pose (kein HTTP-Polling)
    - Acceptance-Radius 0.10m -> 0.25m (realistisch fuer Skid-Steer + RTK-Rauschen)
    - Overshoot-Detector: Wegpunkt gilt als erreicht wenn Min-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
    [config.py, main.py, vehicle_geometry.py]
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2026-05-09 Innen-Rad-Garantie + Nav-Status-Feedback und Tuning der Wegpunkt-Annahme
    Navigation:
    - Innen-Rad-Garantie (min_inner_wheel_speed=0.50): das kurveninnere Skid-Rad
    rollt mind. mit 50% von max_joystick vorwärts (~75 µs über Neutral, sicher
    außerhalb der ESC-Totzone), Fahrzeug fährt einen Bogen statt zu pivotieren
    → kein Scrubbing/Umgraben auf Rasen.
    - Heading-aware inner_floor: Roll-Boost wird mit
    heading_factor = max(0, 1 - |err|/90°) skaliert; bei ≥90° collapse auf 0
    (enger Wenderadius ohne Scrubbing). Der No-Reverse-Schutz
    forward ≥ |turn|·ratio bleibt immer aktiv.
    - acceptance_radius_m 0.10 → 0.25 (Skid-Steer-Limit + RTK-Rauschen) plus
    Overshoot-Detector: engag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
    [config.py, main.py]
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2026-06-19 Fix ODrive sensorless brake-resistor overload on stop (0x30/0x10)
    Root cause: stop() sent Set_Input_Vel(0) while the axis was still in
    CLOSED_LOOP_SENSORLESS (state=5). At high RPM (e.g. 5000) this forced
    active braking, dumping the motor's kinetic energy into the brake
    resistor in ~0.5s. The resistor duty-cycle limit tripped
    (ERROR_BRAKE_DUTY_CYCLE 0x20) together with the resulting current
    spike (ERROR_OVER_CURRENT 0x10), latching error=0x30 on node0.
    The latched OVER_CURRENT error cannot be cleared via CAN Clear_Errors
    (0x018) — only a power cycle resets it. Consequently every restart
    after a high-RPM stop failed because the axis was stuck in error-IDLE.
    Fix: stop() now sends Set_Axis_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
    [odrive_mower.py]
2026-06-19 Add ODrive heartbeat feedback to web API
    Previously the web app had no visibility into ODrive axis state: when
    the ODrive latched an error (e.g. OVER_CURRENT 0x10) the /api/status
    still reported mower_error: None, because the ODriveMowerController
    only tracked Python-side CAN-send errors, not the hardware heartbeat.
    Changes:
    - CANHandler._reader_loop now recognises CAN-Simple heartbeat frames
    (cmd 0x01, 8-byte [u32 error LE][u32 state LE]) and dispatches them
    to a new odrive_heartbeat_callback(node_id, error, state).
    - ODriveMowerController.on_heartbeat() stores error/state for the
    configured node_id. On error!=0 it sets last_error to a hex string
    so the existing mower_error field s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
    [main.py, odrive_mower.py]
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2026-07-28 Fix mowing navigation: serpentine rest lanes, single direction rule
    Straight alternating mow lanes had stopped working: the vehicle turned
    hard in both directions and then stood still. Root causes found from the
    real journal logs, not from simulation.
    Navigation controller
    - The counter-rotating pivot introduced as a fix never rotated the real
    vehicle: x=-0.50/y=0.0 held for over four minutes with the heading
    stuck in a 1.5 degree noise band. Removed. Rolling alignment around a
    near-stationary track is restored for both directions - that one is
    proven in the same logs (29.7 -> 1.3 degrees in 11 s).
    - Turning and driving forward at once does not converge on this vehicle
    once the tu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
    [config.py]
2026-07-30 Hold mowing plan on RTK loss instead of aborting it
    Trees along a field edge push the RTK fix to FLOAT for a few seconds at
    a time. The plan executor treated a single sample below FIXED as fatal:
    navigation.stop() plus state=rtk_lost, which discards waypoint index and
    track progress and needs a manual restart. On a field ringed by trees
    that ends a mowing run every few lanes.
    Freeze navigation with pause() instead, which keeps waypoint index and
    track progress intact, and continue at the same spot once the fix has
    held for rtk_resume_stable_s. Only after rtk_lost_timeout_s does the
    hard abort happen as before. Driving on a FLOAT solution stays
    forbidden - the vehicle holds position while it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
    [config.py]
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2026-08-07 Make contour and rest-lane plans drivable for a skid-steer
    Mowing plans contained geometry the vehicle cannot follow. Contour rings
    tighten towards the inside (curvature ~ 1/radius, on the meadow up to
    818 deg/m) while the UGV manages roughly 10-15 deg/m rolling, and
    transitions regularly demanded turns the controller rejects at its 45 deg
    heading block.
    Planner side: skip rings above max_lane_curvature_deg_per_m (20 deg/m,
    counted as skipped_curved_lanes) and mow the area further in with straight
    lanes; drop rest lanes below MIN_REST_LANE_LENGTH_M; order and anchor rest
    lane candidates so a run continues where the vehicle already is.
    Execution side: choose a ring start whose tangent match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
    [configure_odrive_dc_current_limit.py, configure_odrive_undervoltage.py]
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2026-08-07 Stop the vehicle when the mower deck fails, and fix the stalls behind it
    On 07.08. the deck died mid-plan and the vehicle mowed nothing for 20
    minutes while the UI still said "Maeher ein". Root cause: odrive 0.5.4
    dispatches every property access to libfibre and waits in
    concurrent.futures.Future.result() with no timeout, so a board that stops
    answering parks the calling thread permanently. No watchdog feeds followed,
    the ODrives disarmed the blades themselves (all three latched 0x800), and
    nothing on the host noticed.
    Mower supervision
    - Register the central system stop for every transport. It hung on the CAN
    branch, so a deck fault over USB stopped only the blades while the plan
    kept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
    [config.py, main.py, odrive_mower.py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]
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2026-08-09 Detect an NTRIP socket that went quiet but stayed open
    The caster can stop sending RTCM while leaving the connection established.
    Nothing in the client noticed: it only ever reconnected on a socket error,
    so RTK sat on a plain GPS fix until the server-side timeout finally dropped
    the connection roughly seven minutes later.
    The client now tracks the time of the last received byte and treats a
    connection without data for longer than the configured threshold as dead,
    reconnecting instead of waiting. The bridge reports the same age so the
    stall is visible from the outside rather than only in the fix quality. TCP
    keepalive is enabled on the socket so a connection that died on the network
    is noti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
    [config.py, gps_ntrip_bridge.py, ntrip_client.py]
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2026-08-09 Push a notification when a fault stops the vehicle
    A fault turns the state red in the web interface, but that only helps while
    someone is looking. A vehicle standing in the garden stayed unnoticed for
    hours. The same information now goes to the phone over ntfy.
    Three places report, which together cover every stop:
    - SafetyMonitor.trigger_system_stop: safety bar, CAN outage, ODrive fault,
    SensorHub timeout - reported with the actual cause, not just "stopped".
    A motion hold is reported only once it outlasts motion_hold_after_s;
    short telemetry gaps pause the vehicle constantly and clear themselves.
    - The plan status in the web server, evaluated as an edge.
    - The ODrive USB stall in mai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
    [config.py, main.py, safety_monitor.py]
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2026-08-14 Show the battery charge level from the Junctek coulometer
    Bus voltage was the only power reading the vehicle had, and on 8S LiFePO4 it
    is useless as a fuel gauge: 90 % to 20 % of charge spans 0.8 V, while 30 A of
    mowing load already drops 0.75 V. The drive motors hang off a separate PWM
    controller, so their current never reaches the ODrives either and the sag
    cannot be compensated in software.
    Read the shunt-based Junctek KG110F instead. Its BLE side is a CH9141
    transparent serial bridge, but the ASCII protocol documented in the manual
    gets no answer over BLE - the meter pushes a binary format on its own, about
    once per second. Frames run 0xbb .. 0xee and hold BCD values, each directly
    foll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
    [battery_monitor.py, config.py, main.py]
2026-08-14 Mount the Junctek meter and shunt on a swappable snap interface
    The battery holder's base plate is 195 mm and can only be printed flat, so
    reprinting it for every accessory is expensive. Give its three 30x30x3 webs a
    dovetail rail with a latch instead, and hang the accessories off that.
    The rail geometry lives in fusion_snap_interface.py, which also builds the two
    test bodies used to check the fit before committing to a real part. The other
    scripts reuse it: fusion_snap_rail_halterung.py retrofits the rails onto
    "Halterung Batterie v4", and both accessory holders embed the same adapter.
    fusion_montage_baugruppe.py executes the part files and calls their build(),
    so each part has exactly one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
    [asa_halterung_batterie_snap.stl, asa_junctek_halter.stl, asa_shunt_halter.stl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]
2026-08-25 Send the browser only what changed in the status
    The vehicle now hangs on a SIM card, and the status stream was by far the
    largest consumer: the full 5.6 kB status went out ten times a second, about
    200 MB an hour, while almost nothing in it moved between two sends. On top of
    that every joystick nudge triggered a PWM broadcast, and the page polled
    /api/status every two seconds beside the socket that already carried it.
    The server now keeps the last stand it sent and emits only the difference;
    the full stand goes to a client that just connected, or to one whose sequence
    number shows it missed a difference. Numbers are rounded to the precision the
    display actually shows and ages to whole seco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
    [config.py]
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2026-08-25 Let the pose find its way in either network
    The vehicle is about to hang on a mobile router, where it reaches the
    SensorHub directly in the same WLAN. If that router fails and both devices
    fall back to the old network, client isolation separates them again and the
    pose only gets through the NAT hairpin - out to the public address and back.
    One configured address means touching the configuration on every change, in
    exactly the moment nobody thinks of it and the drive is paused. The client now
    takes a list and rotates to the next entry after a run of failures, so every
    combination finds itself, including the mixed one. A short network hiccup must
    not rotate, and a successful response resets t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
    [config.py]
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2026-08-27 Let the route come back to the lane instead of giving up beside it
    A hanging USB call on the mower deck stopped everything and forced the process
    restart it is designed to force. The vehicle came back standing 1.42 m from its
    lane, the route restarted, and fifty milliseconds later it aborted with
    cross_track_stop - without having driven a metre, over a distance the vehicle
    covers by turning on the spot, for a fault that had nothing to do with driving.
    The limit is meant to catch a controller that is losing the lane, not one that
    is still finding it. So the distance alone no longer decides: while it keeps
    getting smaller, the controller is doing its job and gets more time. Only a
    deviation t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
    [config.py]
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2026-08-27 Give the refused ODrive errors a deliberate way out
    The safety reset clears watchdog errors only, and refuses everything else on
    purpose: a machine with blades should not quietly wipe away a real fault. But
    the refusal was a dead end. The errors live in the boards' memory, so the only
    remaining way out was to walk to the vehicle and cut its power - which clears
    them just as thoroughly, only after a walk, and without leaving a record.
    There is now an explicit way to do the same thing. It demands a confirmation
    rather than defaulting to anything, writes down which errors were cleared, and
    sends them as a push message, so a motor that really is failing does not
    disappear quietly. The automatic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
    [odrive_mower.py, odrive_usb_mower.py]
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2026-08-27 Make a motor failure say which failure it was
    0x40 on the axis is an umbrella: it means "the motor object reports an error",
    not which one. It came up several times today, the user restarted each time,
    and the question of why could not be answered - the level below was never read.
    It is read now, but only while an error is standing. Every property is its own
    USB round trip and hanging calls are the known problem here; when a fault is
    latched the deck has stopped anyway, so three more trips cost nothing. The
    motor, encoder, sensorless and board errors then travel with the message:
    ODrive-Heartbeat Fehler: node=0 error=0x00000040 state=1 (motor=0x00001000)
    The CAN path passes no detail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
    [odrive_mower.py, odrive_usb_mower.py]
2026-08-27 Ask the gate driver which fault it actually saw
    DRV_FAULT says the driver chip reported something, and no more. Overcurrent,
    undervoltage on its gate supply and over-temperature all look identical from
    outside - but the chip keeps its own status register, and that one tells them
    apart.
    It is read only when the motor error carries the DRV_FAULT bit, because a
    function call over fibre costs more than a property read and hanging calls are
    the known problem on this path. The raw value always travels with the message
    alongside the decoded names, so a wrong bit mapping here cannot swallow what
    the chip said.
    It matters right now: today the fault hit both axes of one board at the same
    instant whi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
    [odrive_mower.py, odrive_usb_mower.py]
2026-08-27 Let the vehicle turn onto the lane before judging its heading
    The heading block counted poses: three above the limit and the run was over.
    Three poses are a third of a second - shorter than any turn this vehicle makes,
    and the roll alignment that exists for exactly this case sits a few lines below
    the check and never got to run. The pre-flight check then correctly predicted
    an immediate stop and refused whole plans whose approach was entirely normal.
    What decides now is whether the angle shrinks. A large angle at the start of a
    lane is not a fault, it is what turning in looks like. The incident this block
    was built for is still caught: the vehicle that would not rotate for over four
    minutes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
    [config.py]
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2026-08-27 Put the heading block back and let the manoeuvre answer it
    Relaxing it to "keep going while the angle shrinks" was wrong, and the vehicle
    showed why within the hour. The alignment arc took the permission and used it:
    it turned through 115 degrees, cleanly, driving forward the whole time, and
    carried the vehicle from 0.89 m to 3.00 m beside its lane. The load of that
    turn dropped the bus far enough that two independent devices recorded it - the
    ODrive logged DC_BUS_UNDER_VOLTAGE, the SensorHub rebooted.
    A large angle is not something to roll through. It is a case for the approach
    manoeuvre, and that now exists: the block fires quickly again, and plan
    execution answers it by building a fresh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
    [config.py]
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2026-08-27 Show whether the axis was braking when it failed
    Am 28.08. um 00:08 Uhr stoppte das Maehdeck mit
    DC_BUS_OVER_REGEN_CURRENT. Die Klemmenspannung stand bei 26,1 V - kein
    Einbruch. Was fehlte, war der Strom: Achse 0 fuehrte in dem Moment -5,74 A,
    also negatives Moment, also Bremsen. Zu holen war der Wert nur von Hand am
    angehaltenen Dienst.
    Der zuletzt gemessene Iq steht jetzt bei jedem Achsfehler mit in der Meldung.
    Ein negativer Wert ist der direkte Beleg fuer Rueckspeisung; eine glatte Null
    sagt genauso viel und wird deshalb ebenfalls ausgegeben.
    Hardware dazu, nicht im Repo: Auf Board 386132523135 (zwei Messer, kein
    Bremswiderstand) stand dc_max_negative_current auf -2,0 A, also rund 52 W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
    [odrive_mower.py, odrive_usb_mower.py]
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
